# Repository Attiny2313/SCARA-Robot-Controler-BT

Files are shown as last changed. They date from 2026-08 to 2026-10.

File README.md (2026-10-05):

# SCARA Robot Controller

Open-source controller project for the **PyBot SCARA robotic arm** and compatible SCARA robots, based on an **ESP32 D1 Mini**, a custom PCB and Bluetooth gamepad control.

The repository contains firmware, editable EasyEDA electronics sources, Gerber files, technical documentation and 3D-printing resources used in the project.

## Current firmware

The current `main` branch includes:

- manual JOINT and TOOL control,
- TEACH point storage in ESP32 NVS,
- automatic PTP playback,
- AUTO speed override from 50% to 250%,
- startup OLED logo,
- assisted manual Z-axis HOME procedure after every restart,
- software E-STOP latch requiring controller restart,
- Polish, English and Ukrainian source comments,
- servo 2 startup position of 90° and allowed movement range of 90–180°.

## Startup procedure

ARM1 and ARM2 are positioned manually at `0°` before power-up or reset. After the controller starts, the firmware requires the operator to establish the Z-axis zero position:

1. Wait for the 5-second OLED startup logo.
2. Connect the Bluetooth gamepad and leave all controls neutral until the gamepad becomes armed.
3. Use the right stick Y axis to move Z at the reduced startup homing speed.
4. Set the mechanism physically at the intended `Z = 0` position.
5. Release the stick and wait until Z stops.
6. Press **A+B together** to confirm the current position as `Z = 0`.
7. Release A+B and leave the controller neutral again for normal MANUAL control to arm.

Normal MANUAL/AUTO operation and the MODE/TEACH panel buttons remain locked until Z HOME is confirmed.

## Controls

In MANUAL mode, `START` switches between JOINT and TOOL control.

- JOINT: left stick controls ARM1/ARM2, right stick Y controls Z.
- TOOL: left stick controls TCP X/Y, right stick Y controls Z.
- Right stick X controls tool rotation.
- A increases servo 2 angle, B decreases it; servo 2 is limited to 90–180°.
- PCB `MODE` switches MANUAL/AUTO when all axes are stopped.
- PCB `TEACH`: short press stores a point, hold for at least 1.8 s to clear the stored program.

In AUTO mode, `START` performs start/pause/resume. D-pad UP/DOWN changes speed by ±10%, while D-pad LEFT restores 100%.

## PC USB controller

The `dev` firmware also supports an optional desktop controller over USB Serial.
The physical Bluetooth gamepad remains supported; the PC application is a second,
exclusive input source with its own neutral-to-ARM safety procedure and a 600 ms
communication timeout.

Windows quick start:

```powershell
cd pc_controller
.\run_windows.bat
```

The application provides two virtual joysticks, gripper/relay controls, JOINT/TOOL,
MANUAL/AUTO, TEACH, startup Z HOME, AUTO speed controls and live robot position/status.

See [pc_controller/README.md](pc_controller/README.md) for details.

## Documentation

- [Documentation index](docs/README.md)
- [Robot operating instructions – Polish](docs/INSTRUKCJA_OBSLUGI_PL.md)
- [AUTO / TEACH reference](docs/AUTO_TEACH.md)
- [Technical documentation – Polish](docs/DOKUMENTACJA_TECHNICZNA_PL.md)
- [Technical documentation – Ukrainian](docs/DOKUMENTACJA_TECHNICZNA_UA.md)

## Repository contents

- `src/` – ESP32 controller firmware.
- `PCB/` – schematic, Gerbers, silkscreen and PCB documentation.
- `PCB/EasyEDA/` – editable EasyEDA schematic and PCB source files.
- `3DPrinting/` – printable mechanical parts.
- `docs/` – operating and technical documentation.

## Build and upload

1. Install Visual Studio Code.
2. Install the PlatformIO extension.
3. Download or clone this repository.
4. Open the project folder in PlatformIO.
5. Connect the ESP32.
6. Build and upload the firmware.

## Credits

### PyBot / jjRobots

The mechanical construction of this robot is based on the **PyBot SCARA Robotic Arm** by **jjRobots**.

Many thanks to jjRobots for publishing the original mechanical design, printable parts and assembly concept that formed the mechanical basis of this project.

- https://www.jjrobots.com/scara-robotic-arm-by-jjrobots/
- https://cults3d.com/en/3d-model/gadget/scara-robotic-arm-open-source-with-control-app

### Alternative gripper

The alternative gripper is based on **Robot Gripper 9g Micro Servo** by **yisparyan**:

- https://www.thingiverse.com/thing:715525

Many thanks to yisparyan for sharing the design with the robotics community.

## License

Original content created for this repository is released under the **MIT License**, unless otherwise marked. This includes the original controller firmware, project documentation and original project files.

Third-party material keeps its original license:

- PyBot-derived mechanical geometry: **CC BY-NC-SA** as published by jjRobots.
- Alternative gripper derived from Thingiverse thing 715525 by yisparyan: **CC BY**.
- External software dependencies retain their own upstream licenses.

Because the PyBot mechanical design includes a **NonCommercial** restriction, those particular third-party 3D assets are not relicensed under MIT and should not be treated as commercially unrestricted open-source content.

See [`LICENSE`](LICENSE), [`THIRD_PARTY_NOTICES.md`](THIRD_PARTY_NOTICES.md) and [`3DPrinting/README.md`](3DPrinting/README.md) for details.

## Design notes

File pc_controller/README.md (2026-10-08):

# SCARA Remote (PC / USB)

A small desktop controller for the SCARA firmware. It communicates with the ESP32
through the same USB serial port used by PlatformIO / Serial Monitor.

## Requirements

- Python 3.10+ recommended
- Tkinter (included with the standard Windows Python installer)
- pyserial

Install the dependency:

```powershell
cd pc_controller
py -m pip install -r requirements.txt
```

Run directly:

```powershell
py SCARA_Remote.py
```

On Windows you can also double-click `run_windows.bat`. It checks for `pyserial`,
installs it from `requirements.txt` when needed, and starts the controller.

Close PlatformIO Serial Monitor before connecting the application because only one
program can normally own the COM port at a time.

## Connection and safety

1. Connect the ESP32 over USB.
2. Start `SCARA_Remote.py`.
3. Select the ESP32 COM port and press **Połącz**.
4. The application performs the `PCHELLO` handshake automatically.
5. Leave both virtual joysticks and all buttons neutral for at least 300 ms.
6. The status changes from **SAFE** to **ARMED**.
7. After every ESP32 restart, establish Z HOME before normal MANUAL operation.

The firmware expects a fresh `PCPAD` packet continuously. If packets stop for more
than 600 ms, manual motion is stopped. If AUTO is running, it is paused.

The physical E-STOP remains authoritative.

## Controls

- Left virtual joystick: ARM1/ARM2 in JOINT, TCP X/Y in TOOL.
- Right virtual joystick: rotation on X and Z on Y.
- **A / B**: gripper.
- **X**: relay.
- **START**: JOINT / TOOL in MANUAL; start / pause / resume in AUTO.
- **MODE**: MANUAL / AUTO.
- **TEACH / Zapisz punkt**: sends a dedicated save command to the ESP32.
- **KASUJ PROGRAM**: asks for confirmation and sends a dedicated clear command.
- The physical PCB TEACH button still keeps its original behavior: short press saves, hold at least 1.8 s clears.
- **HOME Z A+B**: confirms startup Z HOME when Z is stopped.
- AUTO D-pad: up/down changes speed, left restores 100%.

Keyboard shortcuts:

- `W A S D` - left joystick
- `I J K L` - right joystick
- `Q / E` - A / B
- `R` - relay
- `Space` - START
- `M` - MODE
- `T` - TEACH
- `H` - A+B for startup Z HOME
- Arrow keys - AUTO D-pad

## Serial protocol

The desktop app sends:

```text
PCHELLO
PCPAD,LX,LY,RX,RY,BUTTONS,DPAD
PCTEACH
PCCLEAR
PCBYE
```

Axes are integers from `-1000` to `1000`.

Button mask:

- bit 0 = A
- bit 1 = B
- bit 2 = X
- bit 3 = START
- bit 4 = MODE
- bit 5 = TEACH

D-pad mask:

- bit 0 = UP
- bit 1 = DOWN
- bit 2 = LEFT
- bit 3 = RIGHT

The firmware returns machine-readable status lines beginning with `PCSTATE,`.

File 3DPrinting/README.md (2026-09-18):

# 3D printing files

This directory contains printable files used by the SCARA project. Some files are based on third-party designs and therefore keep their original licenses.

## `Parts set.3mf`

The robot mechanical construction is based on the **PyBot SCARA Robotic Arm** by **jjRobots**.

Original project:
- https://www.jjrobots.com/scara-robotic-arm-by-jjrobots/
- https://cults3d.com/en/3d-model/gadget/scara-robotic-arm-open-source-with-control-app

The PyBot design is published under **Creative Commons Attribution-NonCommercial-ShareAlike (CC BY-NC-SA)**. Any geometry originating from or derived from PyBot remains under that upstream license.

Many thanks to **jjRobots** for the original mechanical design and for making the project available to the maker and robotics community.

## `Alternative gripper.3mf`

The alternative gripper is based on **Robot Gripper 9g Micro Servo** by **yisparyan**:

- https://www.thingiverse.com/thing:715525

The original gripper is published under **Creative Commons Attribution (CC BY)**. Attribution to yisparyan and the original Thingiverse design must be retained when redistributing this file or derivatives.

Many thanks to **yisparyan** for sharing the gripper design.

## Important

The repository root MIT license does not override the licenses of the third-party models listed above. See `../THIRD_PARTY_NOTICES.md` for the complete attribution and license summary.

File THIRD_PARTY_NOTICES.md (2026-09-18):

# Third-party notices and credits

This repository contains original work from the SCARA Robot Controller project as well as material based on third-party open designs. The root `LICENSE` (MIT) applies only to original project content unless a file or directory is explicitly identified below as third-party material.

## PyBot / jjRobots mechanical design

The mechanical construction of this project is based on the **PyBot SCARA Robotic Arm** created by **jjRobots**.

We would like to thank jjRobots for publishing the original mechanical design, printable parts and assembly concept that made this project possible.

Sources:
- https://www.jjrobots.com/scara-robotic-arm-by-jjrobots/
- https://cults3d.com/en/3d-model/gadget/scara-robotic-arm-open-source-with-control-app

The published PyBot 3D design is distributed under **Creative Commons Attribution-NonCommercial-ShareAlike (CC BY-NC-SA)**. The source page retrieved for this project does not identify the Creative Commons version number, so this notice intentionally does not assume one.

Any PyBot-derived geometry included in this repository remains subject to the original PyBot license and is **not relicensed under MIT**.

## Alternative gripper – yisparyan / Thingiverse 715525

The alternative gripper used in this project is based on **Robot Gripper 9g Micro Servo** by **yisparyan**:

- https://www.thingiverse.com/thing:715525

Thank you to yisparyan for publishing the gripper design and making it available for reuse.

The original model is published under **Creative Commons Attribution (CC BY)**. The source information retrieved for this project does not identify the Creative Commons version number, so this notice intentionally does not assume one.

The file `3DPrinting/Alternative gripper.3mf` is therefore subject to the attribution requirements of the original CC BY license and is **not relicensed under MIT**.

## External software libraries

Libraries and frameworks referenced by `platformio.ini`, including Arduino/ESP32, Bluepad32, FastAccelStepper, ESP32Servo, Adafruit GFX and Adafruit SSD1306, remain subject to their own upstream licenses. They are not relicensed by this repository.

## License scope summary

- Original firmware, PCB-related project files, documentation and other original project material: **MIT License**, unless otherwise marked.
- PyBot-derived mechanical geometry: **CC BY-NC-SA**, as published by jjRobots.
- Alternative gripper derived from Thingiverse thing 715525 by yisparyan: **CC BY**, as published by the original author.
- External dependencies: their respective upstream licenses.

If an upstream license notice conflicts with this summary, the upstream license notice takes precedence for that third-party material.

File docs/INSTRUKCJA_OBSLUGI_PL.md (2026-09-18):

# INSTRUKCJA OBSŁUGI ROBOTA SCARA

## 1. Przeznaczenie

Robot jest edukacyjnym manipulatorem SCARA przeznaczonym do nauki programowania, automatyki, robotyki, kinematyki i pracy metodą TEACH. Sterowanie odbywa się z wykorzystaniem ESP32, dedykowanej płytki PCB, silników krokowych, dwóch serwomechanizmów i kontrolera Bluetooth.

Urządzenie ma charakter dydaktyczny i eksperymentalny. Nie jest certyfikowanym robotem przemysłowym.

## 2. Elementy sterowania

Robot posiada:

- kontroler Bluetooth,
- przycisk `MODE` na PCB,
- przycisk `TEACH` na PCB,
- E-STOP,
- diodę Bluetooth,
- diodę STATUS,
- diodę ERROR,
- wyświetlacz OLED 128×64.

## 3. Pozycja startowa

Przed włączeniem zasilania lub wykonaniem resetu należy ręcznie ustawić:

- ARM1: `0°`,
- ARM2: `0°`.

Oś Z nie musi być wcześniej ustawiona dokładnie na zero. Jej punkt HOME ustala się po uruchomieniu z wykorzystaniem pada.

Pozycje startowe serw:

- serwo 1 – obrót narzędzia: `90°`,
- serwo 2 – chwytak: `90°`.

Zakres serwa 2 jest ograniczony programowo do `90–180°`.

## 4. Uruchomienie robota

1. Sprawdź, czy w zasięgu robota nie znajdują się osoby ani przedmioty mogące wejść w kolizję z ramieniem.
2. Ustaw ręcznie ARM1 i ARM2 na `0°`.
3. Zwolnij E-STOP.
4. Włącz zasilanie lub zresetuj ESP32.
5. OLED przez około 5 s wyświetli logo startowe.
6. Następnie pojawi się ekran `SET Z HOME`.
7. Połącz pad Bluetooth ze sterownikiem.
8. Nie dotykaj analogów ani przycisków przez co najmniej 300 ms, aż pad zostanie uzbrojony.
9. Wykonaj procedurę HOME osi Z opisaną w następnym rozdziale.

Do momentu zatwierdzenia HOME Z normalne sterowanie, `MODE` i `TEACH` pozostają zablokowane.

## 5. Ustawianie HOME osi Z

Podczas startowej procedury HOME Z:

- prawy analog Y steruje wyłącznie osią Z,
- maksymalna prędkość ruchu wynosi około `1.5 mm/s`,
- normalne programowe ograniczenie `0–300 mm` nie jest jeszcze używane, ponieważ sterownik nie zna pozycji absolutnej.

Procedura:

1. Poruszaj osią Z prawym analogiem Y.
2. Ustaw mechanicznie pozycję, która ma odpowiadać `Z = 0`.
3. Puść analog.
4. Poczekaj, aż oś Z całkowicie się zatrzyma.
5. Naciśnij jednocześnie `A+B`.
6. Sterownik przypisze aktualnej pozycji wartość `Z = 0.00 mm`.
7. Puść oba przyciski.
8. Pozostaw pad neutralnie przez około 300 ms, aby ponownie uzbroić normalne sterowanie MANUAL.

Po zatwierdzeniu Z HOME nie należy ręcznie przestawiać osi ani ramion. Sterownik nie ma enkoderów i nie wykryje takiej zmiany.

## 6. Tryb MANUAL – JOINT

Po uruchomieniu robot pracuje w trybie MANUAL. `START` na padzie przełącza między `JOINT` i `TOOL`.

W trybie JOINT sterowanie jest bezpośrednie:

| Element pada | Funkcja |
|---|---|
| Lewy analog X | ARM1 |
| Lewy analog Y | ARM2 |
| Prawy analog Y | Oś Z |
| Prawy analog X | Obrót narzędzia – serwo 1 |
| A | Zwiększenie kąta serwa 2 |
| B | Zmniejszenie kąta serwa 2 |
| START | Przełączenie JOINT / TOOL |

Programowe zakresy osi:

- ARM1: `−105° ... +105°`,
- ARM2: `−125° ... +125°`,
- Z: `0 ... 300 mm`,
- serwo 1: `0 ... 180°`,
- serwo 2: `90 ... 180°`.

## 7. Tryb MANUAL – TOOL

W trybie TOOL operator steruje pozycją końcówki TCP w płaszczyźnie XY, a sterownik sam przelicza wymagane kąty ARM1 i ARM2 przy pomocy kinematyki odwrotnej.

| Element pada | Funkcja |
|---|---|
| Lewy analog X | TCP w osi X |
| Lewy analog Y | TCP w osi Y |
| Prawy analog Y | Oś Z |
| Prawy analog X | Obrót narzędzia |
| A / B | Zmiana kąta serwa 2 |
| START | Powrót do JOINT |

Jeżeli żądany punkt XY znajduje się poza przestrzenią roboczą lub rozwiązanie kinematyki jest niedozwolone, ruch zostanie odrzucony i może zapalić się dioda ERROR.

## 8. Zapisywanie punktów TEACH

Punkty można zapisywać tylko w MANUAL i przy zatrzymanych osiach.

Krótko naciśnij przycisk `TEACH` na PCB, aby zapisać aktualny punkt.

Zapisywane są:

- pozycja ARM1,
- pozycja ARM2,
- pozycja Z,
- pozycja serwa 1,
- pozycja serwa 2,
- czas postoju punktu.

Sterownik przechowuje maksymalnie 20 punktów. Punkty są zapisywane w pamięci NVS i pozostają po odłączeniu zasilania.

Aby skasować cały program, przytrzymaj `TEACH` przez co najmniej `1.8 s`.

## 9. Tryb AUTO

Do AUTO można przejść tylko przy zatrzymanych osiach.

1. Zatrzymaj robota.
2. Naciśnij `MODE` na PCB.
3. Dioda STATUS powinna wskazać tryb AUTO.
4. Naciśnij `START` na padzie, aby rozpocząć program.

`START` w AUTO działa kolejno jako:

- start,
- pauza,
- wznowienie.

Program odtwarza zapisane punkty metodą PTP i domyślnie pracuje w pętli.

## 10. Regulacja prędkości AUTO

Prędkość AUTO można zmieniać D-padem:

- D-pad góra: `+10%`,
- D-pad dół: `−10%`,
- D-pad lewo: powrót do `100%`.

Dostępny zakres to `50–250%`.

Bazowe prędkości wynoszą:

- ARM1: `20°/s`,
- ARM2: `20°/s`,
- Z: `3.0 mm/s`.

Zmiana procentu zaczyna obowiązywać od kolejnego punktu PTP i skaluje wszystkie trzy główne osie.

## 11. Zatrzymanie programu AUTO

Naciśnięcie `START` podczas ruchu przełącza AUTO w PAUSE.

Po ponownym naciśnięciu `START` program jest wznawiany od bieżącego punktu.

Rozłączenie pada podczas AUTO również powoduje pauzę programu.

## 12. E-STOP

E-STOP należy nacisnąć natychmiast w przypadku:

- zagrożenia kolizją,
- niekontrolowanego ruchu,
- zablokowania mechaniki,
- problemu z napędem,
- zagrożenia dla operatora lub urządzenia.

Po aktywacji E-STOP firmware:

- zatrzymuje generowanie kroków,
- blokuje ruch,
- ustawia AUTO w stan FAULT,
- zapala sygnalizację błędu.

Po E-STOP wymagany jest restart sterownika. Po restarcie należy ponownie ustawić ARM1/ARM2 na `0°` i wykonać HOME Z.

## 13. Sygnalizacja

### LED Bluetooth

- światło ciągłe – pad połączony,
- miganie – brak połączenia z padem.

### LED STATUS

- świeci w trybie AUTO,
- zgaszona w MANUAL.

### LED ERROR

Może sygnalizować m.in.:

- timeout pada,
- niedozwolony punkt TOOL / błąd IK,
- E-STOP,
- FAULT AUTO.

### OLED

OLED pokazuje zależnie od stanu m.in.:

- ekran startowy,
- procedurę `SET Z HOME`,
- stan połączenia Bluetooth,
- uzbrojenie pada,
- tryb MANUAL/AUTO,
- JOINT/TOOL,
- położenie osi,
- liczbę punktów TEACH,
- stan programu AUTO,
- procent prędkości AUTO.

## 14. Utrata kroków i pozycja robota

Pozycja robota jest obliczana z liczników kroków silników. Sterownik nie otrzymuje sprzężenia zwrotnego z enkoderów.

Jeżeli silnik zgubi kroki:

- pozycja programowa przestaje odpowiadać rzeczywistej,
- zapis kolejnych punktów TEACH może być błędny,
- AUTO może pojechać do innego miejsca niż oczekiwane.

W takiej sytuacji należy zatrzymać robota i wykonać restart oraz ponowne ustawienie HOME.

## 15. Zasady bezpiecznej pracy

- Nie wkładaj rąk w przestrzeń roboczą podczas ruchu.
- Nie zmieniaj ręcznie położenia osi po ustaleniu HOME.
- Nie zapisuj punktu TEACH podczas ruchu.
- Nie przełączaj MANUAL/AUTO podczas ruchu.
- Pierwsze odtworzenie nowego programu wykonuj z obniżoną prędkością AUTO.
- Obserwuj przewody, paski, śrubę Z i chwytak pod kątem kolizji.
- Po każdej zmianie mechanicznej lub zmianie przełożenia zweryfikuj parametry firmware.
- Nie odłączaj silnika krokowego od sterownika przy załączonym zasilaniu.
- E-STOP powinien być zawsze łatwo dostępny.

## 16. Zalecana procedura pierwszego uruchomienia programu

1. Uruchom robota i wykonaj HOME Z.
2. Pozostań w MANUAL.
3. Sprawdź każdy kierunek ruchu osi przy małym wychyleniu analogu.
4. Sprawdź zakres serw.
5. Zapisz 2–3 bezpieczne punkty TEACH z dużym zapasem od przeszkód.
6. Przejdź do AUTO.
7. Ustaw prędkość na `50%`.
8. Uruchom program i trzymaj rękę w pobliżu E-STOP.
9. Po potwierdzeniu poprawnego przebiegu stopniowo zwiększaj prędkość.

## 17. Wyłączenie robota

1. Zatrzymaj ruch.
2. Jeżeli działa AUTO, przełącz go w PAUSE lub wróć do MANUAL.
3. Ustaw mechanikę w bezpiecznej pozycji.
4. Wyłącz zasilanie.

Po kolejnym włączeniu zawsze należy ponownie wykonać procedurę HOME osi Z.

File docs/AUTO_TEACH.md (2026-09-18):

# AUTO / TEACH – aktualny firmware `main`

## Pozycja HOME

Robot nie wykonuje automatycznego homingu wszystkich osi.

Pozycja startowa jest ustalana w dwóch etapach:

- ARM1: operator ręcznie ustawia mechanikę na `0°` przed włączeniem zasilania lub resetem,
- ARM2: operator ręcznie ustawia mechanikę na `0°` przed włączeniem zasilania lub resetem,
- Z: po restarcie operator ustawia fizyczne zero osią sterowaną z pada i zatwierdza je kombinacją `A+B`.

### Startowe ustawianie Z HOME

Po uruchomieniu sterownika:

1. OLED wyświetla logo przez 5 s.
2. Następnie pojawia się ekran `SET Z HOME`.
3. Pad musi być połączony i uzbrojony przez pozostawienie wszystkich wejść w neutralnym położeniu przez 300 ms.
4. Prawy analog Y steruje wyłącznie osią Z z prędkością maksymalną `1.5 mm/s`.
5. Po puszczeniu analogu Z jest natychmiast zatrzymywana.
6. Po ustawieniu mechanicznego zera operator, przy zatrzymanej osi, naciska jednocześnie `A+B`.
7. Bieżąca pozycja licznika kroków zostaje wtedy ustawiona jako `Z = 0.00 mm`.
8. Pad jest ponownie rozbrajany; po puszczeniu `A+B` trzeba pozostawić go neutralnie przez 300 ms.

Do chwili zatwierdzenia Z HOME normalne sterowanie MANUAL/AUTO oraz przyciski MODE i TEACH są zablokowane.

## Tryby pracy

Sterownik ma dwa niezależne poziomy trybów:

- `OperatingMode::MANUAL` / `OperatingMode::AUTO`,
- w MANUAL: `ControlMode::JOINT` / `ControlMode::TOOL`.

JOINT/TOOL określa sposób ręcznego prowadzenia robota, a AUTO jest osobnym trybem pracy.

## Przyciski na PCB

### MODE

Przełącza `MANUAL <-> AUTO`.

Zmiana jest odrzucana, gdy którakolwiek oś jest w ruchu. Po przejściu z AUTO do MANUAL pad musi ponownie przejść neutralne uzbrojenie.

### TEACH

Działa tylko w MANUAL i przy zatrzymanych osiach.

- krótkie naciśnięcie: zapis aktualnego punktu,
- przytrzymanie `>= 1.8 s`: wyczyszczenie całego programu.

Punkt zapisuje:

- rzeczywistą pozycję ARM1,
- rzeczywistą pozycję ARM2,
- rzeczywistą pozycję Z,
- pozycję serwa obrotu narzędzia,
- pozycję serwa 2 / chwytaka,
- czas postoju `dwellMs`.

Program może zawierać maksymalnie 20 punktów. Punkty są przechowywane w NVS ESP32 i pozostają po wyłączeniu zasilania.

## Pad – MANUAL

`START` przełącza JOINT / TOOL.

### JOINT

- lewy analog X – ARM1,
- lewy analog Y – ARM2,
- prawy analog Y – Z,
- prawy analog X – obrót narzędzia,
- A – zwiększa kąt serwa 2,
- B – zmniejsza kąt serwa 2.

### TOOL

- lewy analog X/Y – ruch TCP w X/Y przez kinematykę odwrotną,
- prawy analog Y – Z,
- prawy analog X – obrót narzędzia,
- A/B – zmiana kąta serwa 2.

Po połączeniu pada wymagane jest 300 ms neutralnych wejść przed uzbrojeniem ruchu.

### Zakresy serw

- serwo obrotu narzędzia: `0 ... 180°`, pozycja startowa `90°`,
- serwo 2 / chwytak: `90 ... 180°`, pozycja startowa `90°`.

## Pad – AUTO

`START` działa jako:

- IDLE -> START,
- RUN -> PAUSE,
- PAUSED -> RESUME.

Regulacja prędkości całego ruchu w AUTO:

- D-pad góra: `+10%`,
- D-pad dół: `-10%`,
- D-pad lewo: powrót do `100%`,
- zakres regulacji: `50% ... 250%`,
- regulacja skaluje ARM1, ARM2 oraz Z,
- nowa wartość obowiązuje od następnego punktu PTP; bieżący ruch nie jest przeliczany w locie.

Bazowo oba ramiona w AUTO mają `20 deg/s`, a oś Z `3.0 mm/s`. Przykładowo przy `200%` ramiona mają bazową prędkość `40 deg/s`, a Z `6.0 mm/s`.

Sterownik nie nakłada dodatkowego programowego limitu częstotliwości STEP; rzeczywista granica wynika z możliwości napędu, sterownika i mechaniki.

Utrata pada podczas AUTO przełącza program w PAUSE.

## Cykl AUTO

AUTO odtwarza zapisane punkty jako ruch PTP. Dla każdego punktu:

1. ustawiane są cele serw,
2. obliczane są odległości wszystkich trzech osi,
3. dobierane są częstotliwości STEP tak, aby osie w przybliżeniu kończyły ruch w tym samym czasie,
4. sterownik czeka nieblokująco na zakończenie wszystkich osi,
5. wykonywany jest `dwellMs`,
6. uruchamiany jest kolejny punkt.

Domyślnie program pracuje w pętli (`AUTO_LOOP_PROGRAM = true`).

## Sygnalizacja

- LED Bluetooth: świeci ciągle przy połączonym padzie, miga przy braku połączenia,
- LED STATUS: świeci w trybie AUTO,
- LED ERROR: sygnalizuje m.in. timeout pada, błąd IK, E-STOP lub FAULT AUTO,
- OLED: pokazuje tryb, stan pada, położenia osi, liczbę punktów i stan AUTO.

## Bezpieczeństwo

- E-STOP natychmiast zatrzymuje generowanie kroków i ustawia AUTO w `FAULT`.
- Po E-STOP wymagany jest restart sterownika.
- AUTO nie jest zależne od `gamepadArmed`; blokada `gamepadArmed` dotyczy ruchu ręcznego.
- Do AUTO wykorzystywana jest pozycja liczona z `FastAccelStepper::getCurrentPosition()`.
- Sterownik nie ma enkoderów osi, dlatego utrata kroków powoduje utratę zgodności pozycji programowej z mechaniczną.
- Po każdym restarcie należy ponownie wykonać procedurę Z HOME.

## Kolejny etap

Obecna wersja AUTO realizuje PTP. Możliwym kolejnym rozszerzeniem jest interpolacja `LIN`, w której TCP jest dzielony na krótkie odcinki XYZ, a dla kolejnych próbek wykonywana jest kinematyka odwrotna.

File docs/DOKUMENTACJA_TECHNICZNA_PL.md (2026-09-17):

# DOKUMENTACJA TECHNICZNA
## ROBOTYCZNE RAMIĘ SCARA
### Projekt „Robotyka bez granic”

**Typ urządzenia:** edukacyjne ramię robotyczne SCARA 3 DOF + chwytak 2 DOF  
**Sterownik:** ESP32 D1 Mini / WeMos D1 Mini ESP32  
**Sterowanie:** kontroler Bluetooth + przyciski na płytce  
**Oprogramowanie:** C++ / Arduino Framework / PlatformIO  
**Repozytorium:** `Attiny2313/SCARA-Robot-Controler-BT`  
**Gałąź odpowiadająca niniejszemu opisowi:** `dev`  
**Bazowy commit firmware/config:** `3dcf2272da6c95ba952772bd750d242ef21eb560`  

> Dokument opisuje rzeczywistą wersję projektu rozwijaną w repozytorium. Dane pochodzące z projektu bazowego PyBot zostały oddzielone od parametrów wynikających z aktualnej konstrukcji i programu sterującego.

---

# 1. CEL PROJEKTU

Celem projektu jest wykonanie, uruchomienie i zaprogramowanie edukacyjnego robota typu SCARA (Selective Compliance Assembly Robot Arm), przeznaczonego do nauki zagadnień z zakresu mechaniki, elektroniki, automatyki, robotyki, programowania oraz technologii druku 3D.

Robot umożliwia:

- ręczne sterowanie poszczególnymi osiami,
- sterowanie położeniem końcówki roboczej w układzie kartezjańskim,
- sterowanie chwytakiem,
- zapisywanie punktów metodą TEACH,
- automatyczne odtwarzanie zapisanej sekwencji ruchów,
- realizację zadań typu Pick and Place,
- dalszą rozbudowę o dodatkowe czujniki, system wizyjny i inne narzędzia robocze.

Projekt ma charakter edukacyjny i eksperymentalny. Nie jest urządzeniem przemysłowym ani certyfikowanym robotem przeznaczonym do pracy w środowisku produkcyjnym.

---

# 2. CHARAKTERYSTYKA ROBOTA

Robot jest manipulatorem typu SCARA, którego główna część wykonawcza składa się z:

- osi obrotowej ARM1,
- osi obrotowej ARM2,
- liniowej osi pionowej Z,
- serwomechanizmu obrotu chwytaka,
- serwomechanizmu otwierania i zamykania chwytaka.

Za ruch trzech głównych osi odpowiadają silniki krokowe NEMA 17. Ruch obrotowy chwytaka i jego otwieranie realizują serwomechanizmy.

Konstrukcja mechaniczna bazuje na rozwiązaniach projektu PyBot i wykorzystuje elementy wykonane metodą druku 3D oraz standardowe elementy mechaniczne stosowane m.in. w drukarkach 3D.

Sterowanie realizuje mikrokontroler ESP32 współpracujący z dedykowaną płytką PCB. ESP32 komunikuje się z bezprzewodowym kontrolerem poprzez Bluetooth i samodzielnie realizuje logikę sterowania, kinematykę, generację trajektorii PTP, obsługę TEACH/AUTO oraz zabezpieczenia programowe.

Komputer nie jest wymagany do normalnej pracy robota. Jest wykorzystywany do programowania, aktualizacji firmware oraz diagnostyki przez port szeregowy.

---

# 3. PARAMETRY TECHNICZNE

## 3.1. Parametry konstrukcji i sterowania

| Parametr | Wartość |
|---|---:|
| Typ robota | SCARA |
| Liczba głównych osi | 3 |
| Osie robocze | ARM1, ARM2, Z |
| Dodatkowe osie chwytaka | 2 |
| Silniki główne | 3 × NEMA 17 |
| Kąt pełnego kroku silnika | 1,8° |
| Liczba pełnych kroków na obrót | 200 |
| Mikrokrok | 1/16 |
| Serwomechanizmy | 2 × klasy SG90/MG90/MG92R |
| Sterownik główny | ESP32 D1 Mini |
| Sterowniki silników | A4988 |
| Środowisko programistyczne | PlatformIO / Visual Studio Code |
| Framework | Arduino |
| Język programu | C++ |
| Komunikacja z padem | Bluetooth / Bluepad32 |

## 3.2. Parametry wykorzystywane przez aktualny firmware

| Parametr | Wartość |
|---|---:|
| Długość członu ARM1 | 91,61 mm |
| Długość członu ARM2 | 97,528 mm |
| Przełożenie ARM1 | 4,5 |
| Przełożenie ARM2 | 7,280 |
| Skok śruby osi Z | 2,0 mm/obr. |
| Przełożenie Z | 1,0 |
| Zakres programowy ARM1 | −105° ... +105° |
| Zakres programowy ARM2 | −125° ... +125° |
| Zakres programowy Z | 0 ... 300 mm |
| Zakres obrotu chwytaka | 0 ... 180° |
| Zakres serwa chwytaka | 15 ... 95° |
| Prędkość ręczna ARM1 | 25°/s |
| Prędkość ręczna ARM2 | 25°/s |
| Prędkość ręczna Z | 3,0 mm/s |
| Prędkość TCP w trybie TOOL | 20 mm/s |
| Bazowa prędkość AUTO ARM1 | 20°/s |
| Bazowa prędkość AUTO ARM2 | 20°/s |
| Bazowa prędkość AUTO Z | 3,0 mm/s |
| Override prędkości AUTO | 50...250% dla ARM1, ARM2 i Z |
| Przyspieszenie ARM1 | 12000 STEP/s² |
| Przyspieszenie ARM2 | 5000 STEP/s² |
| Przyspieszenie Z | 6000 STEP/s² |
| Liczba punktów programu TEACH | maks. 20 |

## 3.3. Parametry wymagające pomiaru rzeczywistego egzemplarza

Nie należy bez dodatkowych pomiarów przyjmować wartości deklarowanych dla bazowego projektu PyBot jako parametrów gotowego robota.

W szczególności wymagają pomiaru:

- rzeczywista masa robota,
- rzeczywista przestrzeń robocza,
- rzeczywista powtarzalność pozycjonowania,
- maksymalny bezpieczny udźwig,
- maksymalne praktyczne prędkości osi,
- dokładność pozycjonowania TCP.

Do czasu wykonania prób odbiorczych wartości te powinny być traktowane jako „do wyznaczenia”.

---

# 4. BUDOWA MECHANICZNA

## 4.1. Podstawa

Podstawa stanowi element nośny całej konstrukcji. Mocowane są do niej m.in.:

- prowadnice osi Z,
- napędy,
- elementy przekładni pasowych,
- elektronika sterująca,
- elementy zabezpieczające przewody.

Podstawa powinna zapewniać sztywność konstrukcji oraz możliwość stabilnego ustawienia robota na stanowisku.

## 4.2. Pierwszy człon ramienia – ARM1

Pierwszy człon łączy podstawę z centralnym przegubem robota. Jego ruch zmienia kierunek całego manipulatora w płaszczyźnie XY.

Napęd realizowany jest silnikiem krokowym poprzez przekładnię pasową.

## 4.3. Drugi człon ramienia – ARM2

Drugi człon łączy pierwszy człon z końcówką roboczą. Wspólnie z osią ARM1 określa położenie TCP w płaszczyźnie XY.

Ruch realizowany jest niezależnym napędem krokowym poprzez układ przekładni pasowych.

## 4.4. Oś pionowa Z

Oś Z realizuje ruch pionowy końcówki roboczej. Napęd odbywa się za pomocą silnika krokowego i śruby o skoku 2 mm/obrót.

Ze względu na dużą liczbę kroków przypadających na 1 mm ruchu oraz ryzyko gubienia kroków, oś Z pracuje z wyraźnie niższą prędkością niż osie obrotowe.

## 4.5. Chwytak

Chwytak jest wyposażony w dwa serwomechanizmy:

- serwo obrotu narzędzia,
- serwo otwierania i zamykania chwytaka.

Położenia serw mogą być zapisywane razem z punktami programu TEACH.

---

# 5. UKŁAD NAPĘDOWY

## 5.1. Silniki krokowe

Każda z trzech głównych osi korzysta z silnika NEMA 17 o kącie pełnego kroku 1,8°.

Pełny obrót odpowiada:

`360° / 1,8° = 200 kroków`

Przy zastosowaniu mikrokroku 1/16:

`200 × 16 = 3200 mikrokroków na obrót silnika`

Dodatkowo liczba kroków roboczych jest zależna od przełożenia danej osi.

Dla osi Z, przy skoku śruby 2 mm/obrót i mikrokroku 1/16:

`3200 / 2 = 1600 kroków/mm`

Wartość ta jest wykorzystywana przez firmware do przeliczania położenia osi Z.

## 5.2. Sterowniki A4988

Sterowniki A4988 odpowiadają za zasilanie i sterowanie silników krokowych. Każdy sterownik otrzymuje z ESP32 sygnały:

- STEP,
- DIR.

Należy prawidłowo ustawić prąd sterowników zgodnie z zastosowanymi silnikami i chłodzeniem.

Nie wolno podłączać ani odłączać silnika krokowego przy załączonym zasilaniu sterownika.

---

# 6. UKŁAD ELEKTRYCZNY I ELEKTRONICZNY

## 6.1. Główne elementy

Układ elektroniczny zawiera:

- ESP32 D1 Mini,
- 3 sterowniki A4988,
- przetwornicę LM2596,
- złącza silników,
- złącza serwomechanizmów,
- przyciski TEACH i MODE,
- obwód E-STOP,
- diody sygnalizacyjne,
- wyświetlacz OLED SSD1306 128×64 I2C,
- złącza krańcówek,
- elementy bierne i zabezpieczające.

Dokumentacja płytki PCB znajduje się w katalogu `PCB` repozytorium.

## 6.2. Przypisanie wejść i wyjść ESP32

| Funkcja | GPIO |
|---|---:|
| STEP ARM1 | 13 |
| DIR ARM1 | 26 |
| STEP ARM2 | 23 |
| DIR ARM2 | 14 |
| STEP Z | 18 |
| DIR Z | 19 |
| Servo ROTATE | 27 |
| Servo GRIP | 32 |
| TEACH | 25 |
| MODE | 33 |
| E-STOP | 39 |
| Krańcówka Z | 34 |
| Krańcówka ARM1 | 35 |
| Krańcówka ARM2 | 36 |
| LED Bluetooth | 4 |
| LED ERROR | 16 |
| LED STATUS | 17 |
| I2C SDA (OLED) | 21 |
| I2C SCL (OLED) | 22 |

## 6.3. Krańcówki

Płytka posiada wejścia dla krańcówek osi ARM1, ARM2 i Z.

W aktualnej wersji firmware krańcówki nie realizują automatycznego homingu. Wejścia zostały zachowane sprzętowo na potrzeby przyszłej rozbudowy.

## 6.4. E-STOP

E-STOP jest elementem bezpieczeństwa układu.

Po jego aktywacji firmware:

- natychmiast zatrzymuje generowanie kroków,
- blokuje sterowanie ręczne,
- ustawia program AUTO w stan FAULT,
- sygnalizuje błąd,
- wymaga restartu sterownika przed ponowną pracą.

Układ powinien być wykonany tak, aby E-STOP nie opierał się wyłącznie na programie, lecz dodatkowo ograniczał możliwość dalszego zasilania lub aktywacji napędów zgodnie z założeniami płytki sterującej.

## 6.5. Wyświetlacz OLED

Sterownik obsługuje wyświetlacz OLED SSD1306 128×64 podłączony przez I2C. Magistrala wykorzystuje GPIO21 jako SDA i GPIO22 jako SCL.

Podczas inicjalizacji firmware automatycznie sprawdza adresy `0x3C` i `0x3D`. Brak wyświetlacza nie blokuje pracy robota — informacja o problemie jest wysyłana przez Serial.

W czasie pracy OLED pokazuje m.in.:

- tryb MANUAL/AUTO i stan programu,
- stan połączenia Bluetooth,
- liczbę zapisanych punktów TEACH,
- override prędkości w AUTO,
- aktualne położenia ARM1, ARM2 i Z,
- pozycję TCP X/Y lub numer aktualnego punktu programu,
- stany błędów, w tym `E-STOP` i `NUM ERR`.

---

# 7. ARCHITEKTURA STEROWANIA

Rzeczywisty przepływ sterowania można przedstawić następująco:

`Pad Bluetooth → Bluepad32 → ESP32 → logika sterowania → kinematyka / AUTO → FastAccelStepper → A4988 → silniki NEMA17`

Równolegle:

`ESP32 → ESP32Servo → serwo obrotu + serwo chwytaka`

ESP32 pełni jednocześnie funkcję:

- odbiornika poleceń,
- sterownika osi,
- sterownika serw,
- układu kinematyki,
- generatora sekwencji AUTO,
- pamięci programu TEACH,
- modułu bezpieczeństwa programowego,
- układu diagnostycznego.

---

# 8. OPROGRAMOWANIE

## 8.1. Środowisko

Program sterujący został przygotowany w języku C++ z wykorzystaniem:

- Arduino Framework,
- PlatformIO,
- Visual Studio Code.

## 8.2. Główne biblioteki

### Bluepad32

Biblioteka odpowiada za obsługę kontrolerów Bluetooth.

### FastAccelStepper

Biblioteka generuje sygnały STEP dla trzech osi i umożliwia definiowanie prędkości, przyspieszeń oraz pozycji.

### ESP32Servo

Biblioteka steruje serwomechanizmami chwytaka.

### Preferences

Biblioteka obsługuje pamięć NVS ESP32. W pamięci zapisywany jest program TEACH, dzięki czemu punkty pozostają dostępne po wyłączeniu zasilania.

### Adafruit GFX / Adafruit SSD1306

Biblioteki odpowiadają za obsługę wyświetlacza OLED SSD1306 128×64, prezentację stanu robota oraz podstawową diagnostykę.

---

# 9. TRYBY PRACY

Sterownik wykorzystuje dwa niezależne poziomy trybów.

## 9.1. Tryb pracy głównej

- `MANUAL`
- `AUTO`

## 9.2. Tryb sterowania ręcznego

W trybie MANUAL dostępne są:

- `JOINT`
- `TOOL`

Dzięki temu wybór JOINT/TOOL nie jest tym samym co wybór MANUAL/AUTO.

---

# 10. STEROWANIE RĘCZNE – JOINT

W trybie JOINT operator steruje bezpośrednio poszczególnymi osiami robota.

Aktualne mapowanie pada:

| Element kontrolera | Funkcja |
|---|---|
| Lewy analog X | ARM1 |
| Lewy analog Y | ARM2 |
| Prawy analog Y | Z |
| Prawy analog X | obrót chwytaka |
| A / B | otwieranie / zamykanie chwytaka |
| START | JOINT / TOOL |

Wartości z analogów są normalizowane i posiadają martwą strefę, aby niewielkie odchylenia drążka nie powodowały ruchu robota.

Po połączeniu kontrolera robot nie zostaje od razu uzbrojony. Wymagane jest około 300 ms neutralnego położenia wszystkich elementów sterujących. Rozwiązanie to zapobiega niekontrolowanemu ruchowi tuż po sparowaniu pada.

---

# 11. STEROWANIE RĘCZNE – TOOL

W trybie TOOL operator nie steruje bezpośrednio kątami ARM1 i ARM2.

Lewy analog zadaje ruch końcówki roboczej w płaszczyźnie XY, a program oblicza wymagane kąty ramion za pomocą kinematyki odwrotnej.

Sterowanie osi Z i chwytakiem pozostaje analogiczne jak w trybie JOINT.

Jeżeli zadany punkt jest poza obszarem osiągalnym lub wymaga przekroczenia limitu osi, polecenie nie jest wykonywane i może zostać zasygnalizowany błąd.

---

# 12. KINEMATYKA

## 12.1. Kinematyka prosta

Dla dwóch ramion SCARA położenie TCP w płaszczyźnie XY wyznaczane jest z zależności:

`X = L1·cos(θ1) + L2·cos(θ1 + θ2)`

`Y = L1·sin(θ1) + L2·sin(θ1 + θ2)`

oraz:

`Z = położenie osi Z`

gdzie:

- `L1` – długość pierwszego członu,
- `L2` – długość drugiego członu,
- `θ1` – kąt ARM1,
- `θ2` – kąt ARM2.

W aktualnej konfiguracji:

- `L1 = 91,61 mm`,
- `L2 = 97,528 mm`.

## 12.2. Kinematyka odwrotna

W trybie TOOL zadawana jest pozycja `(X,Y)`, a program oblicza kąty `θ1` i `θ2`.

Najpierw obliczana jest zależność:

`cos(θ2) = (X² + Y² − L1² − L2²) / (2·L1·L2)`

Jeżeli wynik znajduje się poza zakresem `−1...1`, punkt leży poza geometrycznym obszarem pracy.

Następnie wyznaczane są kąty przegubów. Dla typowego robota dwuprzegubowego istnieją dwie konfiguracje geometryczne, odpowiadające położeniu „łokcia” po dwóch stronach.

Aktualny firmware wykorzystuje jedną z tych konfiguracji (`ELBOW_UP`).

Po obliczeniu kątów sprawdzane są również programowe ograniczenia zakresów ARM1 i ARM2.

---

# 13. POZYCJA HOME I HOMING

Aktualny robot nie wykonuje automatycznego homingu.

Pozycję HOME należy ustawić ręcznie przed włączeniem zasilania lub resetem ESP32.

Firmware przyjmuje następujące wartości startowe:

| Oś | Pozycja HOME |
|---|---:|
| ARM1 | 0° |
| ARM2 | 0° |
| Z | 0 mm |
| Obrót chwytaka | 90° |
| Chwytak | 30° |

Po starcie licznik kroków każdej osi zostaje ustawiony na pozycję odpowiadającą HOME.

Jeżeli mechanika nie została rzeczywiście ustawiona w tej pozycji, wszystkie późniejsze obliczenia położenia będą obarczone błędem.

Automatyczny homing z wykorzystaniem krańcówek jest przewidywany jako możliwe przyszłe rozszerzenie.

---

# 14. FUNKCJA TEACH

Przycisk TEACH na płytce umożliwia zapis aktualnej pozycji robota.

TEACH działa tylko:

- w trybie MANUAL,
- przy zatrzymanych osiach,
- gdy E-STOP nie jest aktywny.

## 14.1. Krótkie naciśnięcie

Zapisuje kolejny punkt programu.

Każdy punkt zawiera:

- pozycję ARM1,
- pozycję ARM2,
- pozycję Z,
- pozycję serwa obrotu chwytaka,
- pozycję serwa chwytaka,
- czas postoju `dwellMs`.

Maksymalna liczba punktów wynosi 20.

## 14.2. Długie naciśnięcie

Przytrzymanie przycisku przez około 1,8 s usuwa cały zapisany program.

## 14.3. Pamięć

Program jest przechowywany w pamięci NVS ESP32. Dzięki temu nie jest tracony po wyłączeniu zasilania.

---

# 15. TRYB AUTO

Przycisk MODE przełącza pracę pomiędzy MANUAL i AUTO.

Zmiana trybu jest możliwa tylko przy zatrzymanych osiach.

W AUTO pad nie służy do bezpośredniego sterowania osiami.

Przycisk START realizuje funkcję:

- IDLE → START,
- RUN → PAUSE,
- PAUSED → RESUME.

AUTO odtwarza punkty zapisane wcześniej funkcją TEACH.

---

# 16. PRZEBIEG CYKLU AUTO

Dla każdego punktu programu wykonywane są następujące działania:

1. ustawienie pozycji docelowych serwomechanizmów,
2. wyznaczenie odległości do przejechania przez ARM1, ARM2 i Z,
3. dobranie prędkości osi,
4. rozpoczęcie ruchu PTP,
5. oczekiwanie na zakończenie ruchu wszystkich osi,
6. odczekanie zadanego czasu postoju,
7. przejście do kolejnego punktu.

W aktualnej konfiguracji program pracuje domyślnie w pętli.

## 16.1. Typ ruchu

Obecna implementacja AUTO realizuje ruch PTP (Point To Point).

Oznacza to, że synchronizowane są czasy przejazdu osi, ale tor TCP pomiędzy punktami nie musi być linią prostą.

Interpolacja liniowa LIN jest przewidywana jako możliwe przyszłe rozszerzenie.

---

# 17. REGULACJA PRĘDKOŚCI W AUTO

W gałęzi `dev` dostępna jest regulacja prędkości całego ruchu w trybie AUTO.

| D-pad | Funkcja |
|---|---|
| góra | +10% |
| dół | −10% |
| lewo | powrót do 100% |

Zakres regulacji:

`50% ... 250%`

Override skaluje bazowe prędkości wszystkich trzech osi: ARM1, ARM2 i Z. Przy 100% wartości bazowe wynoszą odpowiednio 20°/s, 20°/s i 3,0 mm/s.

Zmiana prędkości zaczyna obowiązywać od kolejnego ruchu PTP. Bieżący ruch nie jest przeliczany w locie.

---

# 18. ZABEZPIECZENIA PROGRAMOWE

Firmware zawiera kilka warstw zabezpieczeń i kontroli poprawności danych.

## 18.1. Limity pozycji

Polecenia ruchu są ograniczane do zakresów:

- ARM1: −105° ... +105°,
- ARM2: −125° ... +125°,
- Z: 0 ... 300 mm.

## 18.2. Częstotliwość STEP i prędkość

Aktualny firmware nie stosuje dodatkowych twardych górnych limitów częstotliwości STEP. Częstotliwość STEP wynika z zadanej prędkości osi, przełożenia, mikrokroku oraz override AUTO.

W MANUAL prędkość jest ograniczana do skonfigurowanych prędkości JOG, natomiast w AUTO do bazowych prędkości AUTO pomnożonych przez override 50...250%. Przyspieszenia są realizowane przez FastAccelStepper.

## 18.3. Walidacja wartości numerycznych

Przed przeliczeniami i wydaniem części poleceń ruchu sprawdzane są wartości typu `NaN` i `Inf`. W przypadku wykrycia błędu firmware nie przekazuje nieprawidłowej pozycji do napędów, może zsynchronizować pozycję z licznikami kroków i zgłasza błąd przez Serial/OLED.

## 18.4. Walidacja programu TEACH/NVS

Podczas odczytu programu z NVS sprawdzany jest rozmiar danych oraz poprawność zapisanych punktów. Nieprawidłowy program, np. zawierający `NaN`, `Inf` lub pozycję poza zakresem osi, jest odrzucany i czyszczony.

## 18.5. Timeout pada

W MANUAL brak aktualnych danych z kontrolera przez określony czas powoduje zatrzymanie ruchu i rozbrojenie sterowania.

## 18.6. Neutralne uzbrojenie pada

Po połączeniu kontrolera wymagane jest neutralne położenie elementów sterujących przez około 300 ms przed uzbrojeniem ruchu.

## 18.7. Utrata kontrolera w AUTO

Rozłączenie kontrolera podczas aktywnego cyklu AUTO powoduje przejście programu w PAUSE.

## 18.8. E-STOP

E-STOP zatrzaskuje stan awaryjny do czasu restartu sterownika. Programowo zatrzymywane są generatory kroków, AUTO przechodzi w FAULT, a sterowanie ręczne pozostaje zablokowane.

---

# 19. PROCEDURA MONTAŻU ELEKTRONIKI

1. Sprawdzić PCB pod kątem zwarć, uszkodzeń ścieżek i jakości lutowania.
2. Zweryfikować polaryzację kondensatorów elektrolitycznych i diod.
3. Sprawdzić orientację tranzystorów, układów scalonych i sterowników A4988.
4. Zamontować ESP32 na przewidzianych złączach goldpin.
5. Przed podłączeniem ESP32 i serw ustawić napięcie LM2596 na 5,0 V.
6. Podłączyć przewody silników, serw i elementów panelu zgodnie ze schematem.
7. Uporządkować przewody tak, aby nie kolidowały z ruchomymi częściami.
8. Zapewnić luz przewodów w miejscach ruchu.
9. Zapewnić wentylację A4988 oraz elementów wydzielających ciepło.
10. Sprawdzić działanie E-STOP przed testami ruchu.

---

# 20. PROCEDURA URUCHOMIENIA

Przed pierwszym uruchomieniem:

1. sprawdzić wszystkie połączenia mechaniczne,
2. sprawdzić naciąg pasków,
3. sprawdzić prowadzenie przewodów,
4. sprawdzić poprawność zasilania,
5. ustawić LM2596 na 5,0 V,
6. sprawdzić ustawienie prądów A4988,
7. upewnić się, że obszar pracy robota jest wolny,
8. ręcznie ustawić robot w pozycji HOME,
9. włączyć zasilanie,
10. obserwować diody sygnalizacyjne i komunikaty Serial,
11. połączyć kontroler Bluetooth,
12. pozostawić analogi i przyciski w neutralnym położeniu do czasu uzbrojenia,
13. wykonać krótkie testy pojedynczych osi przy małych wychyleniach analogów,
14. sprawdzić kierunki ruchu,
15. sprawdzić działanie E-STOP,
16. dopiero po poprawnym wykonaniu powyższych testów przejść do pełnego zakresu pracy.

---

# 21. TESTY ODBIORCZE

Zamiast ograniczać testy do stwierdzenia „działa poprawnie”, zaleca się zapisywanie wyników pomiarowych.

## 21.1. Kontrola PCB

**Kryterium:** brak zwarć, zimnych lutów, błędnej orientacji i uszkodzeń.

## 21.2. Kontrola napięcia 5 V

**Kryterium:** napięcie LM2596 ustawione na 5,0 V przed podłączeniem odbiorników wymagających tego napięcia.

## 21.3. Test ARM1

Zadać ruch np. o 30°, 60° i 90° w obu kierunkach.

**Sprawdzić:**

- kierunek,
- płynność,
- brak gubienia kroków,
- zgodność kąta rzeczywistego z zadanym.

## 21.4. Test ARM2

Analogicznie jak dla ARM1.

## 21.5. Test osi Z

Wykonać przejazdy kontrolne np. 5 mm, 10 mm i 20 mm.

Pomiar wykonać suwmiarką lub czujnikiem zegarowym.

## 21.6. Test chwytaka

Sprawdzić:

- pełne otwarcie,
- pełne zamknięcie,
- brak mechanicznego blokowania,
- brak nadmiernego poboru prądu przy dojeździe do ograniczeń.

## 21.7. Test TEACH

Zapisać kilka punktów, wyłączyć zasilanie, uruchomić ponownie i zweryfikować obecność programu.

## 21.8. Test AUTO

Zapisać minimum 5 punktów i uruchomić wielokrotne odtwarzanie.

Sprawdzić:

- osiąganie wszystkich punktów,
- poprawną obsługę serw,
- czasy postoju,
- działanie START/PAUSE/RESUME,
- poprawne przejście do kolejnego cyklu.

## 21.9. Test utraty kontrolera

### MANUAL

Rozłączenie pada powinno zatrzymać sterowanie.

### AUTO

Utrata kontrolera podczas aktywnego cyklu powinna przełączyć program w PAUSE.

## 21.10. Test E-STOP

Po aktywacji E-STOP:

- wszystkie osie powinny zostać zatrzymane,
- stan AUTO powinien przejść w FAULT,
- dalsza praca powinna być niemożliwa do czasu restartu.

## 21.11. Test powtarzalności

Wybrać minimum trzy punkty w przestrzeni roboczej.

Dla każdego wykonać co najmniej 20 dojazdów i zmierzyć rozrzut pozycji TCP.

Na podstawie tych pomiarów można dopiero wpisać rzeczywistą powtarzalność robota.

## 21.12. Test długotrwały

Zaleca się wykonanie co najmniej 30-minutowej pracy cyklicznej.

Należy monitorować:

- temperaturę A4988,
- temperaturę silników,
- temperaturę LM2596,
- stabilność Bluetooth,
- ewentualne gubienie kroków,
- samoczynne resety ESP32.

---

# 22. BEZPIECZEŃSTWO

Podczas pracy nie wolno:

- wkładać rąk w obszar pracy robota,
- zatrzymywać ramienia ręką,
- dotykać poruszających się pasków,
- pracować z uszkodzonymi przewodami,
- podłączać i odłączać silników krokowych przy załączonym zasilaniu,
- pozostawiać robota bez nadzoru podczas testów,
- uruchamiać pełnej prędkości przed zakończeniem testów pojedynczych osi.

Przed pracami serwisowymi należy odłączyć zasilanie.

Ze względu na edukacyjny charakter urządzenia wszystkie testy powinny być prowadzone pod nadzorem osoby znającej budowę stanowiska.

---

# 23. KONSERWACJA

Okresowo należy kontrolować:

- naciąg pasków,
- stan kół pasowych,
- stan łożysk,
- stan prowadnic,
- dokręcenie śrub,
- stan elementów drukowanych 3D,
- prowadzenie przewodów,
- temperaturę silników,
- temperaturę A4988,
- stabilność połączeń złączowych.

Szczególną uwagę należy zwracać na układ napędowy drugiego członu, ponieważ luz paska bezpośrednio wpływa na dokładność i powtarzalność robota.

---

# 24. MOŻLIWOŚCI ROZBUDOWY

Projekt może zostać rozwinięty o:

- automatyczny homing z wykorzystaniem krańcówek,
- interpolację liniową LIN w przestrzeni TCP,
- system wizyjny,
- kamerę do rozpoznawania obiektów,
- czujnik odległości,
- wykrywanie obecności detalu,
- elektromagnes,
- przyssawkę podciśnieniową,
- marker,
- dozownik,
- narzędzie pomiarowe,
- interfejs PC do edycji programów,
- zapis większej liczby programów,
- wybór programu z poziomu panelu,
- raportowanie pozycji i błędów przez Wi-Fi.

---

# 25. PRZYKŁADOWA SEKWENCJA PICK AND PLACE

Przykładowa sekwencja może wyglądać następująco:

`START → pozycja bazowa → przejazd nad detal → Z w dół → zamknięcie chwytaka → Z w górę → przejazd nad miejsce odkładania → Z w dół → otwarcie chwytaka → Z w górę → powrót → STOP`

Sekwencję można zapisać za pomocą funkcji TEACH, a następnie odtwarzać w trybie AUTO.

---

# 26. ZALEŻNOŚĆ PARAMETRÓW MECHANICZNYCH I PROGRAMOWYCH

Zmiana konstrukcji mechanicznej może wymagać modyfikacji firmware.

Przykładowo:

`zmiana długości ramienia → zmiana parametrów kinematyki → zmiana obliczanych kątów → zmiana położenia TCP`

Podobnie:

`zmiana przełożenia → zmiana liczby kroków/stopień → błędna pozycja osi przy starych parametrach`

Dlatego po każdej modyfikacji:

- długości ramion,
- kół pasowych,
- przełożeń,
- śruby osi Z,
- mikrokroku,

należy sprawdzić i w razie potrzeby zaktualizować parametry programu.

---

# 27. WERSJONOWANIE DOKUMENTACJI

Dokumentacja techniczna powinna zawsze wskazywać wersję firmware lub commit repozytorium, do którego się odnosi.

Jest to szczególnie ważne, ponieważ w trakcie rozwoju projektu zmieniały się m.in.:

- prędkości osi,
- przyspieszenia,
- zachowanie przycisków MODE i TEACH,
- obsługa utraty połączenia z padem,
- parametry AUTO,
- zabezpieczenia przed niekontrolowanym ruchem.

Przed wydrukowaniem dokumentacji zaleca się wpisanie:

- numeru rewizji PCB,
- nazwy gałęzi,
- hash commita,
- daty wersji,
- autora dokumentacji.

---

# 28. POCHODZENIE ELEMENTÓW PROJEKTU

Konstrukcja mechaniczna korzysta z rozwiązań i modeli projektu bazowego PyBot, natomiast układ sterowania, płytka PCB, konfiguracja ESP32 i aktualny firmware są rozwijane w ramach niniejszego projektu.

Przed publiczną dystrybucją kompletu materiałów należy zweryfikować warunki licencyjne modeli źródłowych oraz dodać do repozytorium odpowiednie informacje o licencjach i autorach.

---

# 29. PODSUMOWANIE

Projekt „Robotyka bez granic” stanowi kompletne edukacyjne stanowisko mechatroniczne łączące mechanikę, druk 3D, elektronikę, napędy, programowanie mikrokontrolerów, kinematykę robotów oraz zagadnienia automatyzacji.

Aktualna wersja robota umożliwia:

- sterowanie bezprzewodowe,
- ręczne prowadzenie osi w trybie JOINT,
- sterowanie TCP w trybie TOOL,
- zapisywanie punktów TEACH,
- automatyczne odtwarzanie programu PTP,
- regulację prędkości ARM1, ARM2 i Z w AUTO,
- bieżący podgląd stanu na wyświetlaczu OLED,
- trwałe przechowywanie programu w pamięci ESP32,
- zatrzymanie awaryjne oraz dodatkowe zabezpieczenia programowe.

Najważniejszymi dalszymi kierunkami rozwoju są automatyczny homing, interpolacja LIN, pomiar rzeczywistej powtarzalności i udźwigu oraz dalsza rozbudowa interfejsu operatora.

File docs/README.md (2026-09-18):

# Dokumentacja projektu SCARA

Ten katalog zawiera dokumentację eksploatacyjną i techniczną robota SCARA.

## Najważniejsze pliki

- [`INSTRUKCJA_OBSLUGI_PL.md`](INSTRUKCJA_OBSLUGI_PL.md) – instrukcja uruchomienia i obsługi robota.
- [`AUTO_TEACH.md`](AUTO_TEACH.md) – skrócony opis trybów MANUAL, TOOL, TEACH i AUTO.
- [`DOKUMENTACJA_TECHNICZNA_PL.md`](DOKUMENTACJA_TECHNICZNA_PL.md) – pełna dokumentacja techniczna w języku polskim.
- [`DOKUMENTACJA_TECHNICZNA_UA.md`](DOKUMENTACJA_TECHNICZNA_UA.md) – pełna dokumentacja techniczna w języku ukraińskim.
- `DOKUMENTACJA_TECHNICZNA_PL.docx` i `DOKUMENTACJA_TECHNICZNA_UA.docx` – wersje Word przygotowane do druku i dalszej edycji.

## Aktualne zachowanie firmware

Aktualna gałąź `main` zawiera m.in.:

- ręczne ustawianie ARM1 i ARM2 na `0°` przed startem,
- startową procedurę ręcznego HOME osi Z z pada,
- potwierdzenie `Z = 0` przez jednoczesne naciśnięcie `A+B`,
- blokadę normalnej pracy do zatwierdzenia HOME Z,
- logo na OLED przez 5 s po uruchomieniu,
- tryby MANUAL JOINT, MANUAL TOOL i AUTO,
- zapis maksymalnie 20 punktów TEACH do NVS,
- automatyczne odtwarzanie PTP,
- regulację prędkości AUTO 50–250%,
- serwo 2 startujące z `90°` i ograniczone programowo do `90–180°`,
- komentarze w kodzie w językach polskim, angielskim i ukraińskim.

## Ważna uwaga o pozycji osi

Robot nie posiada enkoderów położenia głównych osi. Pozycja jest wyznaczana na podstawie liczników kroków silników. Jeżeli silnik zgubi kroki albo mechanika zostanie przestawiona ręcznie po uruchomieniu, sterownik nie wykryje automatycznie tej różnicy.

Z tego powodu po każdym restarcie należy:

1. ustawić ARM1 i ARM2 w pozycji `0°`,
2. wykonać procedurę HOME osi Z,
3. dopiero potem przejść do TEACH lub AUTO.

## Pliki źródłowe elektroniki

Dokumentacja płytki znajduje się w katalogu [`../PCB`](../PCB), a edytowalne pliki EasyEDA w [`../PCB/EasyEDA`](../PCB/EasyEDA).

## Pliki mechaniczne

Modele do druku 3D znajdują się w [`../3DPrinting`](../3DPrinting). Informacje o pochodzeniu modeli i licencjach są opisane w [`../3DPrinting/README.md`](../3DPrinting/README.md) oraz [`../THIRD_PARTY_NOTICES.md`](../THIRD_PARTY_NOTICES.md).

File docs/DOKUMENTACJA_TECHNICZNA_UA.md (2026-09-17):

# ТЕХНІЧНА ДОКУМЕНТАЦІЯ
## РОБОТИЗОВАНА РУКА SCARA
### Проєкт «Робототехніка без кордонів»

**Тип пристрою:** навчальна роботизована рука SCARA 3 DOF + захват 2 DOF  
**Контролер:** ESP32 D1 Mini / WeMos D1 Mini ESP32  
**Керування:** Bluetooth-контролер + кнопки на платі  
**Програмне забезпечення:** C++ / Arduino Framework / PlatformIO  
**Репозиторій:** `Attiny2313/SCARA-Robot-Controler-BT`  
**Гілка, якій відповідає цей опис:** `dev`  
**Базовий commit firmware/config:** `3dcf2272da6c95ba952772bd750d242ef21eb560`  

> Документ описує фактичну версію проєкту, що розробляється в репозиторії. Дані, що походять із базового проєкту PyBot, відокремлені від параметрів, які випливають із поточної конструкції та керуючої програми.

---

# 1. МЕТА ПРОЄКТУ

Метою проєкту є виготовлення, запуск і програмування навчального робота типу SCARA (Selective Compliance Assembly Robot Arm), призначеного для вивчення питань механіки, електроніки, автоматики, робототехніки, програмування та технологій 3D-друку.

Робот дає змогу:

- вручну керувати окремими осями,
- керувати положенням робочого органу в декартовій системі координат,
- керувати захватом,
- зберігати точки методом TEACH,
- автоматично відтворювати збережену послідовність рухів,
- виконувати завдання типу Pick and Place,
- надалі розширювати систему додатковими датчиками, системою машинного зору та іншими робочими інструментами.

Проєкт має навчальний та експериментальний характер. Він не є промисловим пристроєм або сертифікованим роботом, призначеним для роботи у виробничому середовищі.

---

# 2. ХАРАКТЕРИСТИКА РОБОТА

Робот є маніпулятором типу SCARA, основна виконавча частина якого складається з:

- обертальної осі ARM1,
- обертальної осі ARM2,
- лінійної вертикальної осі Z,
- сервомеханізму обертання захвата,
- сервомеханізму відкривання та закривання захвата.

За рух трьох основних осей відповідають крокові двигуни NEMA 17. Обертання захвата та його відкривання реалізуються сервомеханізмами.

Механічна конструкція базується на рішеннях проєкту PyBot і використовує елементи, виготовлені методом 3D-друку, а також стандартні механічні компоненти, що застосовуються, зокрема, у 3D-принтерах.

Керування реалізує мікроконтролер ESP32, який працює разом із спеціальною платою PCB. ESP32 зв’язується з бездротовим контролером через Bluetooth і самостійно реалізує логіку керування, кінематику, генерацію траєкторії PTP, обслуговування TEACH/AUTO та програмні засоби захисту.

Комп’ютер не потрібен для нормальної роботи робота. Він використовується для програмування, оновлення firmware та діагностики через послідовний порт.

---

# 3. ТЕХНІЧНІ ПАРАМЕТРИ

## 3.1. Параметри конструкції та керування

| Параметр | Значення |
|---|---:|
| Тип робота | SCARA |
| Кількість основних осей | 3 |
| Робочі осі | ARM1, ARM2, Z |
| Додаткові осі захвата | 2 |
| Основні двигуни | 3 × NEMA 17 |
| Кут повного кроку двигуна | 1,8° |
| Кількість повних кроків на оберт | 200 |
| Мікрокрок | 1/16 |
| Сервомеханізми | 2 × класу SG90/MG90/MG92R |
| Основний контролер | ESP32 D1 Mini |
| Драйвери двигунів | A4988 |
| Середовище програмування | PlatformIO / Visual Studio Code |
| Framework | Arduino |
| Мова програми | C++ |
| Зв’язок із геймпадом | Bluetooth / Bluepad32 |

## 3.2. Параметри, що використовуються поточним firmware

| Параметр | Значення |
|---|---:|
| Довжина ланки ARM1 | 91,61 мм |
| Довжина ланки ARM2 | 97,528 мм |
| Передатне відношення ARM1 | 4,5 |
| Передатне відношення ARM2 | 7,280 |
| Крок гвинта осі Z | 2,0 мм/об. |
| Передатне відношення Z | 1,0 |
| Програмний діапазон ARM1 | −105° ... +105° |
| Програмний діапазон ARM2 | −125° ... +125° |
| Програмний діапазон Z | 0 ... 300 мм |
| Діапазон обертання захвата | 0 ... 180° |
| Діапазон серво захвата | 15 ... 95° |
| Ручна швидкість ARM1 | 25°/с |
| Ручна швидкість ARM2 | 25°/с |
| Ручна швидкість Z | 3,0 мм/с |
| Швидкість TCP у режимі TOOL | 20 мм/с |
| Базова швидкість AUTO ARM1 | 20°/с |
| Базова швидкість AUTO ARM2 | 20°/с |
| Базова швидкість AUTO Z | 3,0 мм/с |
| Override швидкості AUTO | 50...250% для ARM1, ARM2 і Z |
| Прискорення ARM1 | 12000 STEP/с² |
| Прискорення ARM2 | 5000 STEP/с² |
| Прискорення Z | 6000 STEP/с² |
| Кількість точок програми TEACH | макс. 20 |

## 3.3. Параметри, що потребують вимірювання реального екземпляра

Не слід без додаткових вимірювань приймати значення, заявлені для базового проєкту PyBot, як параметри готового робота.

Зокрема, потребують вимірювання:

- фактична маса робота,
- фактичний робочий простір,
- фактична повторюваність позиціонування,
- максимальна безпечна вантажопідйомність,
- максимальні практичні швидкості осей,
- точність позиціонування TCP.

До моменту проведення приймальних випробувань ці значення слід вважати такими, що підлягають визначенню.

---

# 4. МЕХАНІЧНА КОНСТРУКЦІЯ

## 4.1. Основа

Основа є несучим елементом усієї конструкції. До неї кріпляться, зокрема:

- напрямні осі Z,
- приводи,
- елементи пасових передач,
- керуюча електроніка,
- елементи захисту кабелів.

Основа повинна забезпечувати жорсткість конструкції та можливість стабільного встановлення робота на робочому місці.

## 4.2. Перша ланка руки – ARM1

Перша ланка з’єднує основу з центральним шарніром робота. Її рух змінює напрямок усього маніпулятора в площині XY.

Привід реалізований кроковим двигуном через пасову передачу.

## 4.3. Друга ланка руки – ARM2

Друга ланка з’єднує першу ланку з робочим органом. Разом з віссю ARM1 вона визначає положення TCP у площині XY.

Рух реалізується незалежним кроковим приводом через систему пасових передач.

## 4.4. Вертикальна вісь Z

Вісь Z забезпечує вертикальний рух робочого органу. Привід здійснюється за допомогою крокового двигуна та гвинта з кроком 2 мм/оберт.

Через велику кількість кроків на 1 мм руху та ризик пропуску кроків вісь Z працює зі значно нижчою швидкістю, ніж обертальні осі.

## 4.5. Захват

Захват оснащений двома сервомеханізмами:

- серво обертання інструмента,
- серво відкривання та закривання захвата.

Положення сервоприводів можуть зберігатися разом із точками програми TEACH.

---

# 5. СИСТЕМА ПРИВОДІВ

## 5.1. Крокові двигуни

Кожна з трьох основних осей використовує двигун NEMA 17 з кутом повного кроку 1,8°.

Повному оберту відповідає:

`360° / 1,8° = 200 кроків`

При використанні мікрокроку 1/16:

`200 × 16 = 3200 мікрокроків на оберт двигуна`

Додатково кількість робочих кроків залежить від передатного відношення конкретної осі.

Для осі Z, за кроку гвинта 2 мм/оберт і мікрокроку 1/16:

`3200 / 2 = 1600 кроків/мм`

Це значення використовується firmware для перерахунку положення осі Z.

## 5.2. Драйвери A4988

Драйвери A4988 відповідають за живлення та керування кроковими двигунами. Кожен драйвер отримує від ESP32 сигнали:

- STEP,
- DIR.

Необхідно правильно налаштувати струм драйверів відповідно до застосованих двигунів і способу охолодження.

Не можна підключати або відключати кроковий двигун при ввімкненому живленні драйвера.

---

# 6. ЕЛЕКТРИЧНА ТА ЕЛЕКТРОННА СИСТЕМА

## 6.1. Основні елементи

Електронна система містить:

- ESP32 D1 Mini,
- 3 драйвери A4988,
- перетворювач LM2596,
- роз’єми двигунів,
- роз’єми сервомеханізмів,
- кнопки TEACH і MODE,
- коло E-STOP,
- сигнальні світлодіоди,
- OLED-дисплей SSD1306 128×64 I2C,
- роз’єми кінцевих вимикачів,
- пасивні та захисні елементи.

Документація плати PCB знаходиться в каталозі `PCB` репозиторію.

## 6.2. Призначення входів і виходів ESP32

| Функція | GPIO |
|---|---:|
| STEP ARM1 | 13 |
| DIR ARM1 | 26 |
| STEP ARM2 | 23 |
| DIR ARM2 | 14 |
| STEP Z | 18 |
| DIR Z | 19 |
| Servo ROTATE | 27 |
| Servo GRIP | 32 |
| TEACH | 25 |
| MODE | 33 |
| E-STOP | 39 |
| Кінцевий вимикач Z | 34 |
| Кінцевий вимикач ARM1 | 35 |
| Кінцевий вимикач ARM2 | 36 |
| LED Bluetooth | 4 |
| LED ERROR | 16 |
| LED STATUS | 17 |
| I2C SDA (OLED) | 21 |
| I2C SCL (OLED) | 22 |

## 6.3. Кінцеві вимикачі

Плата має входи для кінцевих вимикачів осей ARM1, ARM2 і Z.

У поточній версії firmware кінцеві вимикачі не реалізують автоматичний homing. Входи збережені апаратно для майбутнього розширення.

## 6.4. E-STOP

E-STOP є елементом безпеки системи.

Після його активації firmware:

- негайно зупиняє генерацію кроків,
- блокує ручне керування,
- переводить програму AUTO у стан FAULT,
- сигналізує про помилку,
- вимагає перезапуску контролера перед повторною роботою.

Система повинна бути виконана так, щоб E-STOP не покладався виключно на програмне забезпечення, а додатково обмежував можливість подальшого живлення або активації приводів відповідно до концепції керуючої плати.

## 6.5. OLED-дисплей

Контролер підтримує OLED-дисплей SSD1306 128×64, підключений через I2C. Шина використовує GPIO21 як SDA і GPIO22 як SCL.

Під час ініціалізації firmware автоматично перевіряє адреси `0x3C` і `0x3D`. Відсутність дисплея не блокує роботу робота — інформація про проблему передається через Serial.

Під час роботи OLED показує, зокрема:

- режим MANUAL/AUTO і стан програми,
- стан Bluetooth-з’єднання,
- кількість збережених точок TEACH,
- override швидкості в AUTO,
- фактичні положення ARM1, ARM2 і Z,
- положення TCP X/Y або номер поточної точки програми,
- стани помилок, зокрема `E-STOP` і `NUM ERR`.

---

# 7. АРХІТЕКТУРА КЕРУВАННЯ

Фактичний потік керування можна подати так:

`Bluetooth-геймпад → Bluepad32 → ESP32 → логіка керування → кінематика / AUTO → FastAccelStepper → A4988 → двигуни NEMA17`

Паралельно:

`ESP32 → ESP32Servo → серво обертання + серво захвата`

ESP32 одночасно виконує функції:

- приймача команд,
- контролера осей,
- контролера сервоприводів,
- модуля кінематики,
- генератора послідовності AUTO,
- пам’яті програми TEACH,
- програмного модуля безпеки,
- діагностичного модуля.

---

# 8. ПРОГРАМНЕ ЗАБЕЗПЕЧЕННЯ

## 8.1. Середовище

Керуючу програму підготовлено мовою C++ з використанням:

- Arduino Framework,
- PlatformIO,
- Visual Studio Code.

## 8.2. Основні бібліотеки

### Bluepad32

Бібліотека відповідає за обслуговування Bluetooth-контролерів.

### FastAccelStepper

Бібліотека генерує сигнали STEP для трьох осей і дає змогу задавати швидкість, прискорення та положення.

### ESP32Servo

Бібліотека керує сервомеханізмами захвата.

### Preferences

Бібліотека обслуговує пам’ять NVS ESP32. У пам’яті зберігається програма TEACH, завдяки чому точки залишаються доступними після вимкнення живлення.

### Adafruit GFX / Adafruit SSD1306

Бібліотеки відповідають за роботу OLED-дисплея SSD1306 128×64, відображення стану робота та базову діагностику.

---

# 9. РЕЖИМИ РОБОТИ

Контролер використовує два незалежні рівні режимів.

## 9.1. Основний режим роботи

- `MANUAL`
- `AUTO`

## 9.2. Режим ручного керування

У режимі MANUAL доступні:

- `JOINT`
- `TOOL`

Таким чином, вибір JOINT/TOOL не є тим самим, що вибір MANUAL/AUTO.

---

# 10. РУЧНЕ КЕРУВАННЯ – JOINT

У режимі JOINT оператор безпосередньо керує окремими осями робота.

Поточне призначення органів геймпада:

| Елемент контролера | Функція |
|---|---|
| Лівий аналог X | ARM1 |
| Лівий аналог Y | ARM2 |
| Правий аналог Y | Z |
| Правий аналог X | обертання захвата |
| A / B | відкривання / закривання захвата |
| START | JOINT / TOOL |

Значення з аналогових стиків нормалізуються та мають мертву зону, щоб невеликі відхилення стика не спричиняли рух робота.

Після підключення контролера робот не озброюється одразу. Потрібно приблизно 300 мс нейтрального положення всіх органів керування. Це запобігає неконтрольованому руху відразу після спарювання геймпада.

---

# 11. РУЧНЕ КЕРУВАННЯ – TOOL

У режимі TOOL оператор не керує безпосередньо кутами ARM1 і ARM2.

Лівий аналог задає рух робочого органу в площині XY, а програма обчислює необхідні кути плечей за допомогою оберненої кінематики.

Керування віссю Z та захватом залишається аналогічним до режиму JOINT.

Якщо задана точка знаходиться поза досяжною областю або потребує перевищення межі осі, команда не виконується і може бути сигналізована помилка.

---

# 12. КІНЕМАТИКА

## 12.1. Пряма кінематика

Для двох плечей SCARA положення TCP у площині XY визначається залежностями:

`X = L1·cos(θ1) + L2·cos(θ1 + θ2)`

`Y = L1·sin(θ1) + L2·sin(θ1 + θ2)`

та:

`Z = положення осі Z`

де:

- `L1` – довжина першої ланки,
- `L2` – довжина другої ланки,
- `θ1` – кут ARM1,
- `θ2` – кут ARM2.

У поточній конфігурації:

- `L1 = 91,61 мм`,
- `L2 = 97,528 мм`.

## 12.2. Обернена кінематика

У режимі TOOL задається положення `(X,Y)`, а програма обчислює кути `θ1` і `θ2`.

Спочатку обчислюється залежність:

`cos(θ2) = (X² + Y² − L1² − L2²) / (2·L1·L2)`

Якщо результат виходить за межі `−1...1`, точка знаходиться поза геометричною робочою областю.

Потім визначаються кути шарнірів. Для типового двошарнірного робота існують дві геометричні конфігурації, що відповідають положенню «ліктя» з двох боків.

Поточний firmware використовує одну з цих конфігурацій (`ELBOW_UP`).

Після обчислення кутів також перевіряються програмні обмеження діапазонів ARM1 і ARM2.

---

# 13. ПОЛОЖЕННЯ HOME І HOMING

Поточний робот не виконує автоматичний homing.

Положення HOME необхідно встановити вручну перед увімкненням живлення або скиданням ESP32.

Firmware приймає такі стартові значення:

| Вісь | Положення HOME |
|---|---:|
| ARM1 | 0° |
| ARM2 | 0° |
| Z | 0 мм |
| Обертання захвата | 90° |
| Захват | 30° |

Після запуску лічильник кроків кожної осі встановлюється в положення, що відповідає HOME.

Якщо механіка фактично не була встановлена в це положення, усі подальші обчислення положення міститимуть помилку.

Автоматичний homing із використанням кінцевих вимикачів передбачений як можливе майбутнє розширення.

---

# 14. ФУНКЦІЯ TEACH

Кнопка TEACH на платі дає змогу зберегти поточне положення робота.

TEACH працює лише:

- у режимі MANUAL,
- при зупинених осях,
- коли E-STOP не активний.

## 14.1. Коротке натискання

Зберігає наступну точку програми.

Кожна точка містить:

- положення ARM1,
- положення ARM2,
- положення Z,
- положення серво обертання захвата,
- положення серво захвата,
- час паузи `dwellMs`.

Максимальна кількість точок становить 20.

## 14.2. Довге натискання

Утримання кнопки приблизно 1,8 с видаляє всю збережену програму.

## 14.3. Пам’ять

Програма зберігається в пам’яті NVS ESP32. Завдяки цьому вона не втрачається після вимкнення живлення.

---

# 15. РЕЖИМ AUTO

Кнопка MODE перемикає роботу між MANUAL і AUTO.

Зміна режиму можлива лише при зупинених осях.

У AUTO геймпад не використовується для безпосереднього керування осями.

Кнопка START реалізує функції:

- IDLE → START,
- RUN → PAUSE,
- PAUSED → RESUME.

AUTO відтворює точки, раніше збережені функцією TEACH.

---

# 16. ПЕРЕБІГ ЦИКЛУ AUTO

Для кожної точки програми виконуються такі дії:

1. встановлення цільових положень сервомеханізмів,
2. визначення відстані, яку мають пройти ARM1, ARM2 і Z,
3. вибір швидкостей осей,
4. початок руху PTP,
5. очікування завершення руху всіх осей,
6. очікування заданого часу паузи,
7. перехід до наступної точки.

У поточній конфігурації програма за замовчуванням працює циклічно.

## 16.1. Тип руху

Поточна реалізація AUTO виконує рух PTP (Point To Point).

Це означає, що синхронізуються часи переміщення осей, але траєкторія TCP між точками не обов’язково є прямою лінією.

Лінійна інтерполяція LIN передбачена як можливе майбутнє розширення.

---

# 17. РЕГУЛЮВАННЯ ШВИДКОСТІ В AUTO

У гілці `dev` доступне регулювання швидкості всього руху в режимі AUTO.

| D-pad | Функція |
|---|---|
| вгору | +10% |
| вниз | −10% |
| вліво | повернення до 100% |

Діапазон регулювання:

`50% ... 250%`

Override масштабує базові швидкості всіх трьох осей: ARM1, ARM2 і Z. При 100% базові значення становлять відповідно 20°/с, 20°/с і 3,0 мм/с.

Зміна швидкості починає діяти з наступного руху PTP. Поточний рух не перераховується в реальному часі.

---

# 18. ПРОГРАМНІ ЗАСОБИ ЗАХИСТУ

Firmware містить кілька рівнів захисту та перевірки коректності даних.

## 18.1. Межі положення

Команди руху обмежуються діапазонами:

- ARM1: −105° ... +105°,
- ARM2: −125° ... +125°,
- Z: 0 ... 300 мм.

## 18.2. Частота STEP і швидкість

Поточний firmware не використовує додаткових жорстких верхніх обмежень частоти STEP. Частота STEP визначається заданою швидкістю осі, передатним відношенням, мікрокроком та override AUTO.

У MANUAL швидкість обмежується налаштованими швидкостями JOG, а в AUTO — базовими швидкостями AUTO, помноженими на override 50...250%. Прискорення реалізує FastAccelStepper.

## 18.3. Перевірка числових значень

Перед обчисленнями та частиною команд руху перевіряються значення типу `NaN` і `Inf`. У разі виявлення помилки firmware не передає некоректну позицію приводам, може синхронізувати позицію з лічильниками кроків і повідомляє про помилку через Serial/OLED.

## 18.4. Перевірка програми TEACH/NVS

Під час читання програми з NVS перевіряються розмір даних і коректність збережених точок. Некоректна програма, наприклад із `NaN`, `Inf` або позицією поза діапазоном осі, відхиляється та очищується.

## 18.5. Timeout геймпада

У MANUAL відсутність актуальних даних від контролера протягом визначеного часу спричиняє зупинку руху та роззброєння керування.

## 18.6. Нейтральне озброєння геймпада

Після підключення контролера необхідне нейтральне положення органів керування приблизно 300 мс перед активацією руху.

## 18.7. Втрата контролера в AUTO

Відключення контролера під час активного циклу AUTO переводить програму в PAUSE.

## 18.8. E-STOP

E-STOP фіксує аварійний стан до моменту перезапуску контролера. Програмно зупиняються генератори кроків, AUTO переходить у FAULT, а ручне керування залишається заблокованим.

---

# 19. ПРОЦЕДУРА МОНТАЖУ ЕЛЕКТРОНІКИ

1. Перевірити PCB на наявність коротких замикань, пошкоджень доріжок і якість пайки.
2. Перевірити полярність електролітичних конденсаторів і діодів.
3. Перевірити орієнтацію транзисторів, інтегральних схем і драйверів A4988.
4. Встановити ESP32 у передбачені роз’єми goldpin.
5. Перед підключенням ESP32 і сервоприводів встановити напругу LM2596 на 5,0 В.
6. Підключити проводи двигунів, сервоприводів і елементів панелі відповідно до схеми.
7. Упорядкувати проводи так, щоб вони не заважали рухомим частинам.
8. Забезпечити запас довжини проводів у місцях руху.
9. Забезпечити вентиляцію A4988 та елементів, що виділяють тепло.
10. Перевірити роботу E-STOP перед випробуваннями руху.

---

# 20. ПРОЦЕДУРА ЗАПУСКУ

Перед першим запуском:

1. перевірити всі механічні з’єднання,
2. перевірити натяг ременів,
3. перевірити прокладання проводів,
4. перевірити правильність живлення,
5. встановити LM2596 на 5,0 В,
6. перевірити налаштування струмів A4988,
7. переконатися, що робоча зона робота вільна,
8. вручну встановити робота в положення HOME,
9. увімкнути живлення,
10. спостерігати за сигнальними світлодіодами та повідомленнями Serial,
11. підключити Bluetooth-контролер,
12. залишити аналоги та кнопки в нейтральному положенні до моменту озброєння,
13. виконати короткі тести окремих осей при малих відхиленнях аналогів,
14. перевірити напрямки руху,
15. перевірити роботу E-STOP,
16. лише після успішного виконання наведених вище тестів перейти до повного діапазону роботи.

---

# 21. ПРИЙМАЛЬНІ ВИПРОБУВАННЯ

Замість обмеження тестів твердженням «працює правильно» рекомендується записувати результати вимірювань.

## 21.1. Контроль PCB

**Критерій:** відсутність коротких замикань, холодних пайок, неправильної орієнтації та пошкоджень.

## 21.2. Контроль напруги 5 В

**Критерій:** напруга LM2596 встановлена на 5,0 В перед підключенням споживачів, які потребують цієї напруги.

## 21.3. Тест ARM1

Задати рух, наприклад, на 30°, 60° і 90° в обох напрямках.

**Перевірити:**

- напрямок,
- плавність,
- відсутність пропусків кроків,
- відповідність фактичного кута заданому.

## 21.4. Тест ARM2

Аналогічно до ARM1.

## 21.5. Тест осі Z

Виконати контрольні переміщення, наприклад, 5 мм, 10 мм і 20 мм.

Вимірювання виконати штангенциркулем або індикатором годинникового типу.

## 21.6. Тест захвата

Перевірити:

- повне відкриття,
- повне закриття,
- відсутність механічного заклинювання,
- відсутність надмірного споживання струму при досягненні обмежень.

## 21.7. Тест TEACH

Зберегти кілька точок, вимкнути живлення, знову запустити систему та перевірити наявність програми.

## 21.8. Тест AUTO

Зберегти щонайменше 5 точок і запустити багаторазове відтворення.

Перевірити:

- досягнення всіх точок,
- правильну роботу сервоприводів,
- часи пауз,
- роботу START/PAUSE/RESUME,
- правильний перехід до наступного циклу.

## 21.9. Тест втрати контролера

### MANUAL

Відключення геймпада має зупинити керування.

### AUTO

Втрата контролера під час активного циклу повинна перевести програму в PAUSE.

## 21.10. Тест E-STOP

Після активації E-STOP:

- усі осі мають бути зупинені,
- стан AUTO має перейти в FAULT,
- подальша робота має бути неможливою до перезапуску.

## 21.11. Тест повторюваності

Вибрати щонайменше три точки в робочому просторі.

Для кожної виконати щонайменше 20 підходів і виміряти розкид положення TCP.

Лише на основі цих вимірювань можна вказати фактичну повторюваність робота.

## 21.12. Тривалий тест

Рекомендується провести щонайменше 30-хвилинну циклічну роботу.

Необхідно контролювати:

- температуру A4988,
- температуру двигунів,
- температуру LM2596,
- стабільність Bluetooth,
- можливі пропуски кроків,
- самовільні перезавантаження ESP32.

---

# 22. БЕЗПЕКА

Під час роботи заборонено:

- вводити руки в робочу зону робота,
- зупиняти плече рукою,
- торкатися рухомих ременів,
- працювати з пошкодженими проводами,
- підключати та відключати крокові двигуни при ввімкненому живленні,
- залишати робота без нагляду під час тестів,
- запускати повну швидкість до завершення тестів окремих осей.

Перед сервісними роботами необхідно відключити живлення.

Через навчальний характер пристрою всі тести повинні проводитися під наглядом особи, яка знає конструкцію стенда.

---

# 23. ТЕХНІЧНЕ ОБСЛУГОВУВАННЯ

Періодично необхідно контролювати:

- натяг ременів,
- стан шківів,
- стан підшипників,
- стан напрямних,
- затягування гвинтів,
- стан елементів, надрукованих на 3D-принтері,
- прокладання проводів,
- температуру двигунів,
- температуру A4988,
- стабільність з’єднань роз’ємів.

Особливу увагу слід приділяти приводу другої ланки, оскільки люфт ременя безпосередньо впливає на точність і повторюваність робота.

---

# 24. МОЖЛИВОСТІ РОЗШИРЕННЯ

Проєкт може бути розширений такими функціями:

- автоматичний homing із використанням кінцевих вимикачів,
- лінійна інтерполяція LIN у просторі TCP,
- система машинного зору,
- камера для розпізнавання об’єктів,
- датчик відстані,
- виявлення наявності деталі,
- електромагніт,
- вакуумна присоска,
- маркер,
- дозатор,
- вимірювальний інструмент,
- інтерфейс PC для редагування програм,
- зберігання більшої кількості програм,
- вибір програми з панелі,
- передавання положення та помилок через Wi-Fi.

---

# 25. ПРИКЛАД ПОСЛІДОВНОСТІ PICK AND PLACE

Приклад послідовності може виглядати так:

`START → базове положення → переміщення над деталлю → Z вниз → закриття захвата → Z вгору → переміщення над місцем укладання → Z вниз → відкриття захвата → Z вгору → повернення → STOP`

Послідовність можна зберегти за допомогою функції TEACH, а потім відтворювати в режимі AUTO.

---

# 26. ВЗАЄМОЗВ’ЯЗОК МЕХАНІЧНИХ І ПРОГРАМНИХ ПАРАМЕТРІВ

Зміна механічної конструкції може потребувати модифікації firmware.

Наприклад:

`зміна довжини плеча → зміна параметрів кінематики → зміна обчислюваних кутів → зміна положення TCP`

Аналогічно:

`зміна передатного відношення → зміна кількості кроків/градус → неправильне положення осі зі старими параметрами`

Тому після кожної модифікації:

- довжини плечей,
- шківів,
- передатних відношень,
- гвинта осі Z,
- мікрокроку,

необхідно перевірити та, за потреби, оновити параметри програми.

---

# 27. ВЕРСІОНУВАННЯ ДОКУМЕНТАЦІЇ

Технічна документація завжди повинна вказувати версію firmware або commit репозиторію, до якого вона належить.

Це особливо важливо, оскільки під час розвитку проєкту змінювалися, зокрема:

- швидкості осей,
- прискорення,
- поведінка кнопок MODE і TEACH,
- обслуговування втрати зв’язку з геймпадом,
- параметри AUTO,
- захист від неконтрольованого руху.

Перед друком документації рекомендується вказати:

- номер ревізії PCB,
- назву гілки,
- hash commit,
- дату версії,
- автора документації.

---

# 28. ПОХОДЖЕННЯ ЕЛЕМЕНТІВ ПРОЄКТУ

Механічна конструкція використовує рішення та моделі базового проєкту PyBot, тоді як система керування, плата PCB, конфігурація ESP32 і поточний firmware розробляються в межах цього проєкту.

Перед публічним розповсюдженням повного комплекту матеріалів необхідно перевірити ліцензійні умови вихідних моделей і додати до репозиторію відповідну інформацію про ліцензії та авторів.

---

# 29. ПІДСУМОК

Проєкт «Робототехніка без кордонів» є комплексним навчальним мехатронним стендом, що поєднує механіку, 3D-друк, електроніку, приводи, програмування мікроконтролерів, кінематику роботів та питання автоматизації.

Поточна версія робота дає змогу:

- бездротове керування,
- ручне керування осями в режимі JOINT,
- керування TCP у режимі TOOL,
- зберігання точок TEACH,
- автоматичне відтворення програми PTP,
- регулювання швидкості ARM1, ARM2 і Z в AUTO,
- поточне відображення стану на OLED-дисплеї,
- постійне зберігання програми в пам’яті ESP32,
- аварійну зупинку та додаткові програмні засоби захисту.

Найважливішими подальшими напрямами розвитку є автоматичний homing, інтерполяція LIN, вимірювання фактичної повторюваності та вантажопідйомності, а також подальший розвиток інтерфейсу оператора.

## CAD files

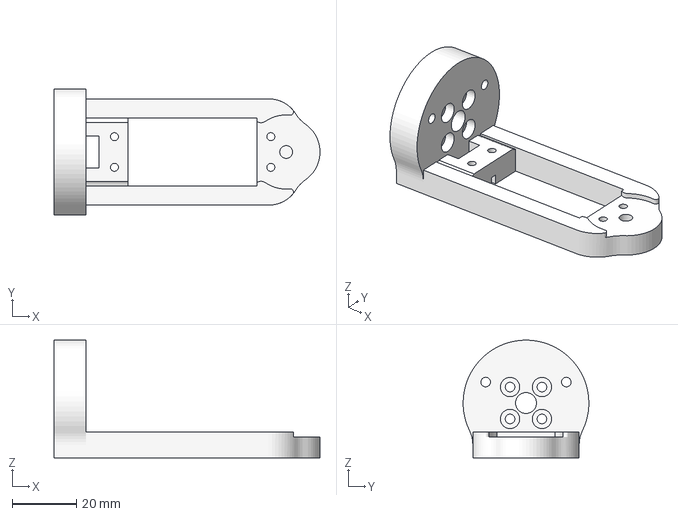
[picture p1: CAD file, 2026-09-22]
3DPrinting/Mantis MG966R Mount.3mf
82.5 x 39.0 x 36.5 mm

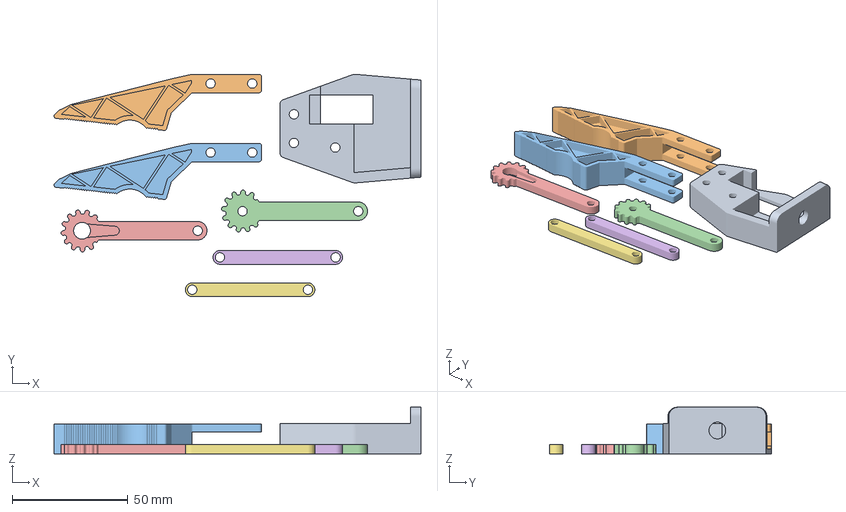
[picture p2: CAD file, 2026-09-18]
3DPrinting/Alternative gripper.3mf
158.6 x 96.1 x 20.1 mm
Base.stl
Claw.stl x 2
Connector_Gear.stl
Servo_Connector_Gear.stl
Connector.stl x 2

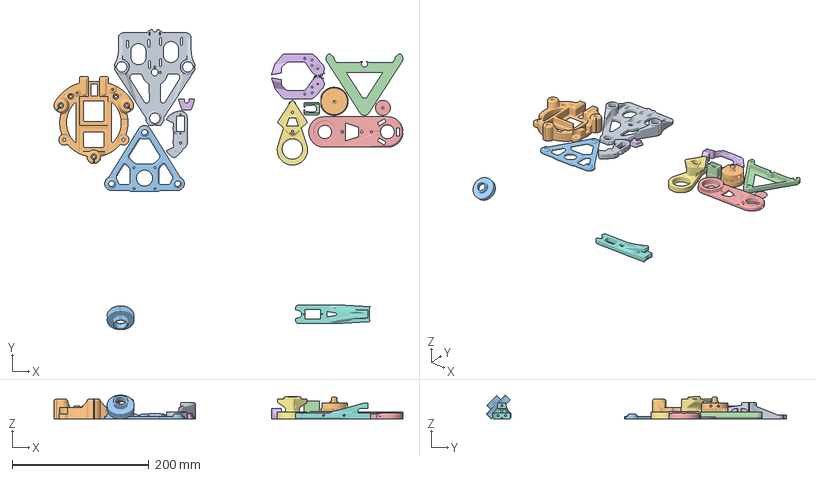
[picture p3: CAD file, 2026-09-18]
3DPrinting/Parts set.3mf
510.4 x 439.3 x 34.9 mm
Z_BASE_[V10.stl
BASEPLATE_[V10.stl
MOTORS_TRIANGLE_[V10.stl
TOP_TRIANGLE_[V10.stl
ARM_TOP_[V9.stl
GRIPPER-_NAILS_[V10.stl
ARM_BOTTOM_[V10.stl
FOREAM_[V10.stl
GRIPPER-_BASE_[V10.stl
ARM_HUB_[V11.stl
REDUCTION_[V10.stl
PEN_HOLDER_[V10.stl
CAP_[V10.stl
CABLES_CAP_[V10.stl

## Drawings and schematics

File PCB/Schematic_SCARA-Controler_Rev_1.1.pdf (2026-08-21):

### GND

### VCCServo

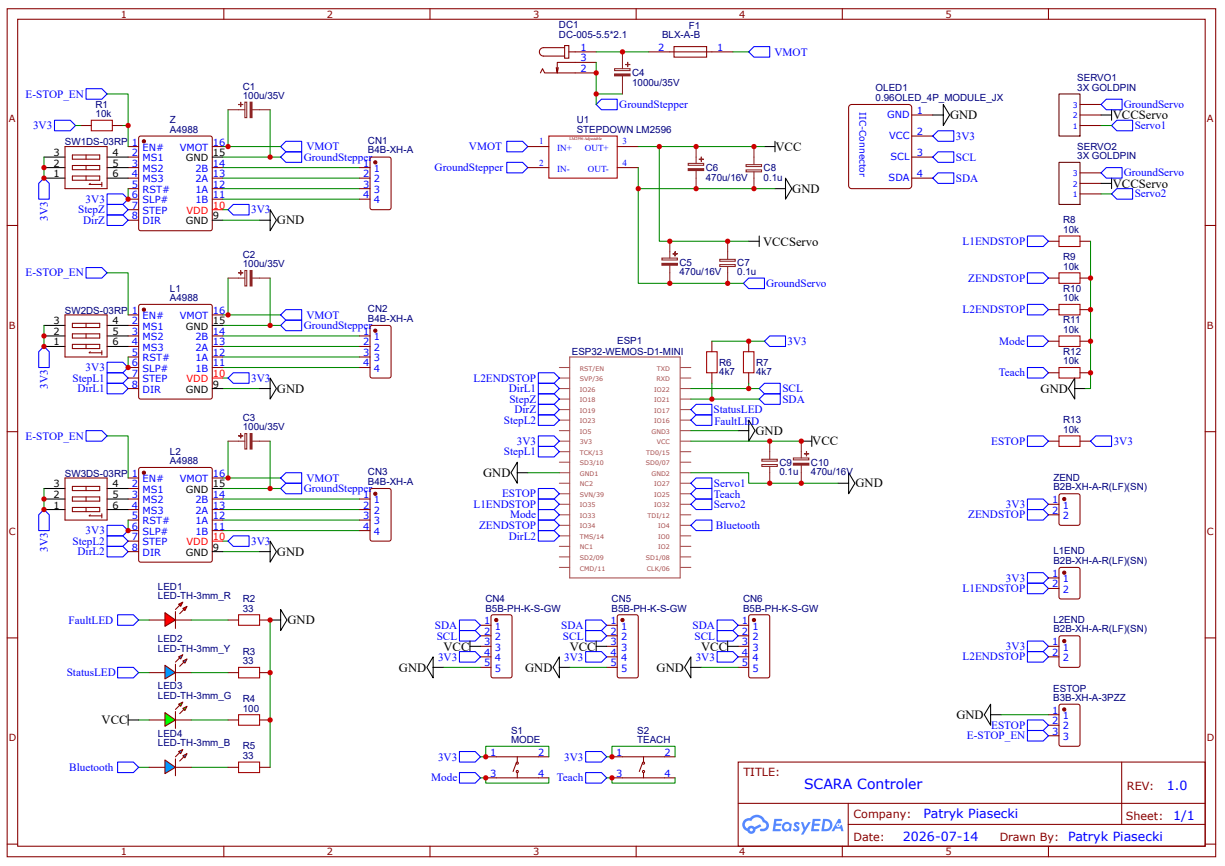
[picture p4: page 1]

Drawn By: Patryk Piasecki

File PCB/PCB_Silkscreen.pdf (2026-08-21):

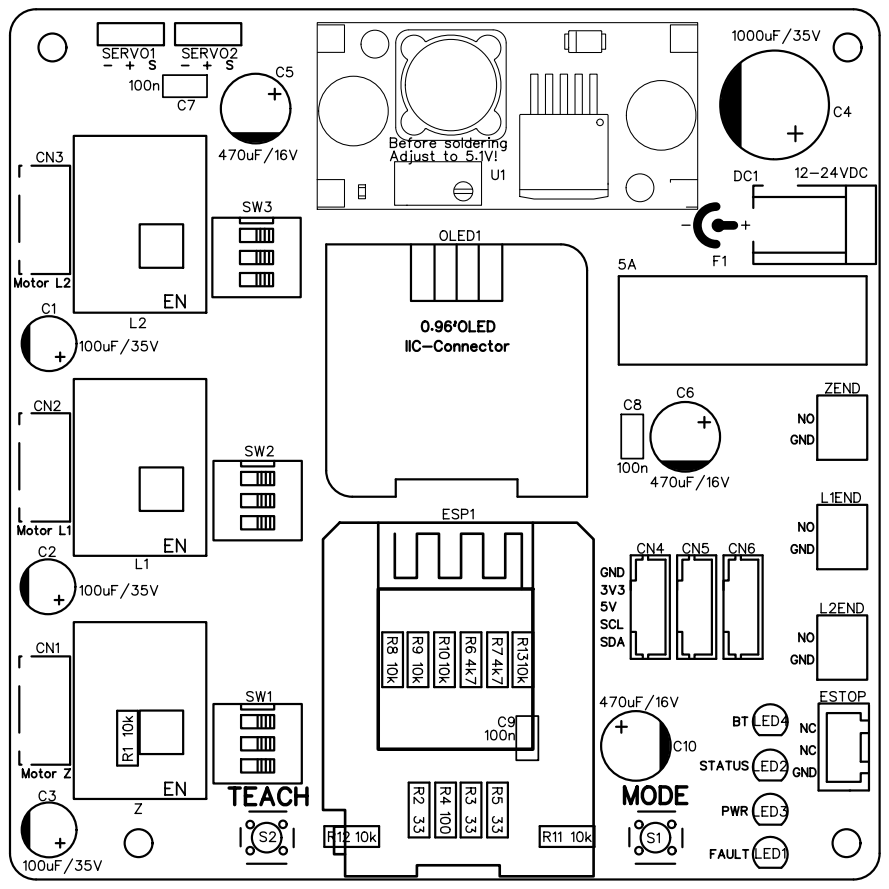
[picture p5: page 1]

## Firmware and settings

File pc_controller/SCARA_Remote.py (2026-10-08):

#!/usr/bin/env python3
"""
SCARA Remote - Windows/Linux PC controller for the ESP32 SCARA firmware.

Protocol:
  PCHELLO
  PCPAD,LX,LY,RX,RY,BUTTONS,DPAD
  PCBYE

Axes are sent as integers from -1000 to 1000.
"""

import math
import time
import tkinter as tk
from tkinter import ttk, messagebox
from collections import deque

import serial
from serial.tools import list_ports


BAUDRATE = 115200
SEND_PERIOD_MS = 50
HELLO_RETRY_S = 0.8

BTN_A = 1 << 0
BTN_B = 1 << 1
BTN_X = 1 << 2
BTN_START = 1 << 3
BTN_MODE = 1 << 4
BTN_TEACH = 1 << 5

DPAD_UP = 1 << 0
DPAD_DOWN = 1 << 1
DPAD_LEFT = 1 << 2
DPAD_RIGHT = 1 << 3


class VirtualJoystick(tk.Canvas):
    def __init__(self, master, title, size=190, **kwargs):
        super().__init__(
            master,
            width=size,
            height=size,
            highlightthickness=1,
            relief="sunken",
            **kwargs,
        )
        self.size = size
        self.center = size / 2
        self.radius = size * 0.36
        self.knob_radius = size * 0.09
        self.x_value = 0.0
        self.y_value = 0.0

        self.create_text(self.center, 14, text=title, font=("Segoe UI", 10, "bold"))
        self.create_oval(
            self.center - self.radius,
            self.center - self.radius,
            self.center + self.radius,
            self.center + self.radius,
            width=2,
        )
        self.create_line(
            self.center - self.radius,
            self.center,
            self.center + self.radius,
            self.center,
        )
        self.create_line(
            self.center,
            self.center - self.radius,
            self.center,
            self.center + self.radius,
        )
        self.knob = self.create_oval(0, 0, 0, 0, width=2)
        self.value_text = self.create_text(
            self.center, self.size - 13, text="X 0.00   Y 0.00"
        )
        self._draw_knob()

        self.bind("<Button-1>", self._move)
        self.bind("<B1-Motion>", self._move)
        self.bind("<ButtonRelease-1>", self._release)

    def _move(self, event):
        dx = event.x - self.center
        dy = event.y - self.center
        distance = math.hypot(dx, dy)
        if distance > self.radius and distance > 0:
            scale = self.radius / distance
            dx *= scale
            dy *= scale

        self.x_value = max(-1.0, min(1.0, dx / self.radius))
        self.y_value = max(-1.0, min(1.0, dy / self.radius))
        self._draw_knob()

    def _release(self, _event=None):
        self.x_value = 0.0
        self.y_value = 0.0
        self._draw_knob()

    def _draw_knob(self):
        x = self.center + self.x_value * self.radius
        y = self.center + self.y_value * self.radius
        r = self.knob_radius
        self.coords(self.knob, x - r, y - r, x + r, y + r)
        self.itemconfigure(
            self.value_text,
            text=f"X {self.x_value:+.2f}   Y {self.y_value:+.2f}",
        )

    def values(self):
        return self.x_value, self.y_value


class ScaraRemote(tk.Tk):
    def __init__(self):
        super().__init__()
        self.title("SCARA Remote - USB")
        self.geometry("930x690")
        self.minsize(850, 620)

        self.ser = None
        self.handshake_ok = False
        self.last_hello = 0.0
        self.rx_buffer = ""
        self.buttons = 0
        self.dpad = 0
        self.keys_down = set()
        self.log_lines = deque(maxlen=120)

        self.port_var = tk.StringVar()
        self.connection_var = tk.StringVar(value="Rozłączony")
        self.arm_var = tk.StringVar(value="SAFE")
        self.work_var = tk.StringVar(value="-")
        self.control_var = tk.StringVar(value="-")
        self.home_var = tk.StringVar(value="-")
        self.estop_var = tk.StringVar(value="-")
        self.relay_var = tk.StringVar(value="-")
        self.points_var = tk.StringVar(value="-")
        self.speed_var = tk.StringVar(value="-")

        self.a1_var = tk.StringVar(value="0.00°")
        self.a2_var = tk.StringVar(value="0.00°")
        self.z_var = tk.StringVar(value="0.00 mm")
        self.x_var = tk.StringVar(value="0.00 mm")
        self.y_var = tk.StringVar(value="0.00 mm")
        self.rot_var = tk.StringVar(value="0.0°")
        self.grip_var = tk.StringVar(value="0.0°")

        self._build_ui()
        self._bind_keys()
        self.refresh_ports()
        self.protocol("WM_DELETE_WINDOW", self.on_close)
        self.after(SEND_PERIOD_MS, self.tick)

    def _build_ui(self):
        top = ttk.Frame(self, padding=10)
        top.pack(fill="x")

        ttk.Label(top, text="Port COM:").pack(side="left")
        self.port_combo = ttk.Combobox(
            top, textvariable=self.port_var, width=24, state="readonly"
        )
        self.port_combo.pack(side="left", padx=(6, 6))
        ttk.Button(top, text="Odśwież", command=self.refresh_ports).pack(side="left")
        self.connect_button = ttk.Button(top, text="Połącz", command=self.toggle_connection)
        self.connect_button.pack(side="left", padx=(6, 14))

        ttk.Label(top, text="Stan:").pack(side="left")
        ttk.Label(top, textvariable=self.connection_var, font=("Segoe UI", 10, "bold")).pack(
            side="left", padx=(5, 0)
        )

        status = ttk.LabelFrame(self, text="Robot", padding=8)
        status.pack(fill="x", padx=10, pady=(0, 8))

        status_items = [
            ("A1", self.a1_var),
            ("A2", self.a2_var),
            ("Z", self.z_var),
            ("TCP X", self.x_var),
            ("TCP Y", self.y_var),
            ("ROT", self.rot_var),
            ("GRIP", self.grip_var),
            ("WORK", self.work_var),
            ("CONTROL", self.control_var),
            ("PC", self.arm_var),
            ("HOME Z", self.home_var),
            ("E-STOP", self.estop_var),
            ("RELAY", self.relay_var),
            ("Punkty", self.points_var),
            ("AUTO", self.speed_var),
        ]

        for i, (name, var) in enumerate(status_items):
            frame = ttk.Frame(status)
            frame.grid(row=i // 8, column=i % 8, padx=8, pady=3, sticky="w")
            ttk.Label(frame, text=f"{name}:").pack(side="left")
            ttk.Label(frame, textvariable=var, font=("Segoe UI", 9, "bold")).pack(
                side="left", padx=(3, 0)
            )

        control = ttk.Frame(self, padding=(10, 0, 10, 0))
        control.pack(fill="both", expand=True)

        left_col = ttk.LabelFrame(control, text="Sterowanie", padding=10)
        left_col.pack(side="left", fill="both", expand=True, padx=(0, 6))

        joy_frame = ttk.Frame(left_col)
        joy_frame.pack()
        self.left_joy = VirtualJoystick(joy_frame, "LEFT: ARM1/ARM2 lub TCP X/Y")
        self.left_joy.pack(side="left", padx=8)
        self.right_joy = VirtualJoystick(joy_frame, "RIGHT: ROT / Z")
        self.right_joy.pack(side="left", padx=8)

        button_frame = ttk.Frame(left_col)
        button_frame.pack(fill="x", pady=(12, 4))

        self._hold_button(button_frame, "A  Grip +", BTN_A).grid(row=0, column=0, padx=4, pady=4)
        self._hold_button(button_frame, "B  Grip -", BTN_B).grid(row=0, column=1, padx=4, pady=4)
        ttk.Button(
            button_frame, text="X  Relay", command=lambda: self.pulse_button(BTN_X)
        ).grid(row=0, column=2, padx=4, pady=4)
        ttk.Button(
            button_frame, text="START  JOINT/TOOL", command=lambda: self.pulse_button(BTN_START)
        ).grid(row=0, column=3, padx=4, pady=4)

        ttk.Button(
            button_frame, text="MODE  MANUAL/AUTO", command=lambda: self.pulse_button(BTN_MODE)
        ).grid(row=1, column=0, padx=4, pady=4)

        ttk.Button(
            button_frame,
            text="TEACH  Zapisz punkt",
            command=self.send_teach_command,
        ).grid(row=1, column=1, padx=4, pady=4, sticky="ew")

        ttk.Button(
            button_frame,
            text="KASUJ PROGRAM",
            command=self.confirm_clear_program,
        ).grid(row=1, column=2, padx=4, pady=4, sticky="ew")

        ttk.Button(
            button_frame,
            text="HOME Z  A+B",
            command=lambda: self.pulse_button(BTN_A | BTN_B, 320),
        ).grid(row=1, column=3, padx=4, pady=4)

        dpad_frame = ttk.LabelFrame(left_col, text="AUTO speed", padding=6)
        dpad_frame.pack(pady=(7, 0))
        ttk.Button(
            dpad_frame, text="▲ +", width=8, command=lambda: self.pulse_dpad(DPAD_UP)
        ).grid(row=0, column=1, padx=3, pady=2)
        ttk.Button(
            dpad_frame, text="◀ 100%", width=8, command=lambda: self.pulse_dpad(DPAD_LEFT)
        ).grid(row=1, column=0, padx=3, pady=2)
        ttk.Button(
            dpad_frame, text="▼ -", width=8, command=lambda: self.pulse_dpad(DPAD_DOWN)
        ).grid(row=1, column=1, padx=3, pady=2)

        help_text = (
            "Klawiatura: WASD = lewy joystick, IJKL = prawy joystick, "
            "Q/E = A/B, R = relay, SPACE = START, M = MODE, T = zapisz punkt, "
            "H = HOME Z (A+B), strzałki = D-pad AUTO.\n"
            "Po połączeniu pozostaw wszystko neutralnie przez chwilę, aż PC zmieni stan SAFE → ARMED."
        )
        ttk.Label(left_col, text=help_text, wraplength=560, justify="left").pack(
            fill="x", pady=(10, 0)
        )

        right_col = ttk.LabelFrame(control, text="Log", padding=6)
        right_col.pack(side="right", fill="both", expand=False, padx=(6, 0))
        self.log = tk.Text(right_col, width=38, height=28, state="disabled", wrap="word")
        self.log.pack(fill="both", expand=True)

        warning = ttk.Label(
            self,
            text=(
                "USB jest dodatkowym źródłem sterowania. Fizyczny E-STOP pozostaje nadrzędny. "
                "Brak pakietów z PC przez 600 ms zatrzymuje ruch."
            ),
            padding=(10, 7),
        )
        warning.pack(fill="x")

    def _hold_button(self, master, text, mask):
        btn = tk.Button(master, text=text)
        btn.bind("<ButtonPress-1>", lambda _e: self.set_button(mask, True))
        btn.bind("<ButtonRelease-1>", lambda _e: self.set_button(mask, False))
        return btn

    def _bind_keys(self):
        self.bind_all("<KeyPress>", self.key_press)
        self.bind_all("<KeyRelease>", self.key_release)

    def key_press(self, event):
        key = event.keysym.lower()
        was_down = key in self.keys_down
        self.keys_down.add(key)

        if key == "q":
            self.set_button(BTN_A, True)
        elif key == "e":
            self.set_button(BTN_B, True)
        elif key == "r":
            self.set_button(BTN_X, True)
        elif key == "space":
            self.set_button(BTN_START, True)
        elif key == "m":
            self.set_button(BTN_MODE, True)
        elif key == "t" and not was_down:
            self.send_teach_command()
        elif key == "h":
            self.set_button(BTN_A | BTN_B, True)
        elif key == "up":
            self.dpad |= DPAD_UP
        elif key == "down":
            self.dpad |= DPAD_DOWN
        elif key == "left":
            self.dpad |= DPAD_LEFT
        elif key == "right":
            self.dpad |= DPAD_RIGHT

    def key_release(self, event):
        key = event.keysym.lower()
        self.keys_down.discard(key)

        if key == "q":
            self.set_button(BTN_A, False)
        elif key == "e":
            self.set_button(BTN_B, False)
        elif key == "r":
            self.set_button(BTN_X, False)
        elif key == "space":
            self.set_button(BTN_START, False)
        elif key == "m":
            self.set_button(BTN_MODE, False)
        elif key == "t":
            pass
        elif key == "h":
            self.set_button(BTN_A | BTN_B, False)
        elif key == "up":
            self.dpad &= ~DPAD_UP
        elif key == "down":
            self.dpad &= ~DPAD_DOWN
        elif key == "left":
            self.dpad &= ~DPAD_LEFT
        elif key == "right":
            self.dpad &= ~DPAD_RIGHT

    def set_button(self, mask, pressed):
        if pressed:
            self.buttons |= mask
        else:
            self.buttons &= ~mask

    def pulse_button(self, mask, duration_ms=160):
        self.set_button(mask, True)
        self.after(duration_ms, lambda: self.set_button(mask, False))

    def pulse_dpad(self, mask, duration_ms=160):
        self.dpad |= mask
        self.after(duration_ms, lambda: setattr(self, "dpad", self.dpad & ~mask))

    def send_teach_command(self):
        if not self.ser or not self.ser.is_open or not self.handshake_ok:
            messagebox.showwarning("SCARA Remote", "Najpierw połącz aplikację z ESP32.")
            return
        self.write_line("PCTEACH")
        self.append_log("PC → ESP32: zapisz punkt TEACH")

    def confirm_clear_program(self):
        if not self.ser or not self.ser.is_open or not self.handshake_ok:
            messagebox.showwarning("SCARA Remote", "Najpierw połącz aplikację z ESP32.")
            return

        if not messagebox.askyesno(
            "SCARA Remote",
            "Skasować cały zapisany program AUTO?\n\nTej operacji nie można cofnąć.",
        ):
            return

        self.write_line("PCCLEAR")
        self.append_log("PC → ESP32: kasuj program AUTO")

    def refresh_ports(self):
        ports = list(list_ports.comports())
        values = [f"{p.device} — {p.description}" for p in ports]
        self.port_combo["values"] = values

        if values and self.port_var.get() not in values:
            preferred = next(
                (
                    value
                    for value in values
                    if any(
                        token in value.lower()
                        for token in ("cp210", "ch340", "usb serial", "uart", "esp32")
                    )
                ),
                values[0],
            )
            self.port_var.set(preferred)

    def selected_port(self):
        value = self.port_var.get().strip()
        if not value:
            return ""
        return value.split(" — ", 1)[0]

    def toggle_connection(self):
        if self.ser and self.ser.is_open:
            self.disconnect()
        else:
            self.connect()

    def connect(self):
        port = self.selected_port()
        if not port:
            messagebox.showwarning("SCARA Remote", "Wybierz port COM.")
            return

        try:
            ser = serial.Serial()
            ser.port = port
            ser.baudrate = BAUDRATE
            ser.timeout = 0
            ser.write_timeout = 0.2
            ser.dtr = False
            ser.rts = False
            ser.open()
            self.ser = ser
        except Exception as exc:
            messagebox.showerror("SCARA Remote", f"Nie można otworzyć {port}:\n{exc}")
            return

        self.handshake_ok = False
        self.last_hello = 0.0
        self.connection_var.set(f"{port} - handshake...")
        self.connect_button.configure(text="Rozłącz")
        self.append_log(f"Połączono z {port}. Oczekiwanie na ESP32...")

    def disconnect(self):
        if self.ser:
            try:
                if self.ser.is_open:
                    if self.handshake_ok:
                        self.write_line("PCPAD,0,0,0,0,0,0")
                        self.write_line("PCBYE")
                    self.ser.close()
            except Exception:
                pass

        self.ser = None
        self.handshake_ok = False
        self.buttons = 0
        self.dpad = 0
        self.connection_var.set("Rozłączony")
        self.connect_button.configure(text="Połącz")
        self.arm_var.set("SAFE")
        self.append_log("Rozłączono.")

    def keyboard_axes(self):
        lx = (-1.0 if "a" in self.keys_down else 0.0) + (
            1.0 if "d" in self.keys_down else 0.0
        )
        ly = (-1.0 if "w" in self.keys_down else 0.0) + (
            1.0 if "s" in self.keys_down else 0.0
        )
        rx = (-1.0 if "j" in self.keys_down else 0.0) + (
            1.0 if "l" in self.keys_down else 0.0
        )
        ry = (-1.0 if "i" in self.keys_down else 0.0) + (
            1.0 if "k" in self.keys_down else 0.0
        )
        return lx, ly, rx, ry

    def current_axes(self):
        mlx, mly = self.left_joy.values()
        mrx, mry = self.right_joy.values()
        klx, kly, krx, kry = self.keyboard_axes()

        lx = klx if klx != 0.0 else mlx
        ly = kly if kly != 0.0 else mly
        rx = krx if krx != 0.0 else mrx
        ry = kry if kry != 0.0 else mry

        return tuple(max(-1.0, min(1.0, value)) for value in (lx, ly, rx, ry))

    def write_line(self, line):
        if not self.ser or not self.ser.is_open:
            return
        try:
            self.ser.write((line + "\n").encode("ascii"))
        except Exception as exc:
            self.append_log(f"Błąd portu: {exc}")
            self.disconnect()

    def send_pad(self):
        lx, ly, rx, ry = self.current_axes()
        values = [int(round(v * 1000.0)) for v in (lx, ly, rx, ry)]
        self.write_line(
            f"PCPAD,{values[0]},{values[1]},{values[2]},{values[3]},"
            f"{self.buttons},{self.dpad}"
        )

    def read_serial(self):
        if not self.ser or not self.ser.is_open:
            return

        try:
            waiting = self.ser.in_waiting
            if waiting <= 0:
                return
            data = self.ser.read(waiting).decode("utf-8", errors="replace")
        except Exception as exc:
            self.append_log(f"Błąd odczytu: {exc}")
            self.disconnect()
            return

        self.rx_buffer += data
        while "\n" in self.rx_buffer:
            line, self.rx_buffer = self.rx_buffer.split("\n", 1)
            line = line.strip("\r").strip()
            if line:
                self.handle_line(line)

    def handle_line(self, line):
        if line == "PCACK,HELLO,1":
            self.handshake_ok = True
            port = self.selected_port()
            self.connection_var.set(f"{port} - połączony")
            self.append_log("ESP32: handshake OK")
            return

        if line == "PCACK,NEED_HELLO,0":
            self.handshake_ok = False
            self.append_log("ESP32 wymaga ponownego handshake.")
            return

        if line.startswith("PCACK,TEACH,"):
            result = line.split(",", 2)[2]
            if result.startswith("OK"):
                self.append_log(f"TEACH OK: {result}")
            else:
                self.append_log(f"TEACH odrzucony: {result}")
            return

        if line.startswith("PCACK,CLEAR,"):
            result = line.split(",", 2)[2]
            if result == "OK":
                self.append_log("Program AUTO skasowany.")
            else:
                self.append_log(f"Kasowanie odrzucone: {result}")
            return

        if line.startswith("PCSTATE,"):
            self.update_status(line)
            return

        self.append_log(line)

    def update_status(self, line):
        fields = {}
        for item in line.split(",")[1:]:
            if "=" in item:
                key, value = item.split("=", 1)
                fields[key] = value

        try:
            self.a1_var.set(f"{float(fields.get('A1', 0)):.2f}°")
            self.a2_var.set(f"{float(fields.get('A2', 0)):.2f}°")
            self.z_var.set(f"{float(fields.get('Z', 0)):.2f} mm")
            self.x_var.set(f"{float(fields.get('X', 0)):.2f} mm")
            self.y_var.set(f"{float(fields.get('Y', 0)):.2f} mm")
            self.rot_var.set(f"{float(fields.get('ROT', 0)):.1f}°")
            self.grip_var.set(f"{float(fields.get('GRIP', 0)):.1f}°")
        except ValueError:
            pass

        self.work_var.set(fields.get("WORK", "-"))
        self.control_var.set(fields.get("CONTROL", "-"))
        self.arm_var.set("ARMED" if fields.get("ARMED") == "1" else "SAFE")
        self.home_var.set("OK" if fields.get("HOMEZ") == "1" else "WYMAGANY")
        self.estop_var.set("AKTYWNY" if fields.get("ESTOP") == "1" else "OK")
        self.relay_var.set("ON" if fields.get("RELAY") == "1" else "OFF")
        self.points_var.set(fields.get("POINTS", "-"))
        speed = fields.get("SPEED", "-")
        self.speed_var.set(f"{speed}%")

    def append_log(self, text):
        timestamp = time.strftime("%H:%M:%S")
        self.log_lines.append(f"[{timestamp}] {text}")
        self.log.configure(state="normal")
        self.log.delete("1.0", "end")
        self.log.insert("end", "\n".join(self.log_lines))
        self.log.see("end")
        self.log.configure(state="disabled")

    def tick(self):
        if self.ser and self.ser.is_open:
            self.read_serial()
            now = time.monotonic()

            if not self.handshake_ok:
                if now - self.last_hello >= HELLO_RETRY_S:
                    self.write_line("PCHELLO")
                    self.last_hello = now
            else:
                self.send_pad()

        self.after(SEND_PERIOD_MS, self.tick)

    def on_close(self):
        self.disconnect()
        self.destroy()


if __name__ == "__main__":
    ScaraRemote().mainloop()

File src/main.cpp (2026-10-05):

// ============================================================
// PL: STEROWNIK ROBOTA SCARA
// EN: SCARA ROBOT CONTROLLER
// UA: КОНТРОЛЕР РОБОТА SCARA
// ============================================================
//
// PL: Implementacja jest podzielona na sekcje .inc, ale wszystkie są dołączane
//     do jednej jednostki kompilacji. Kolejność include ma znaczenie.
// EN: The implementation is split into .inc sections, but all of them are included
//     in a single compilation unit. Include order matters.
// UA: Реалізацію поділено на секції .inc, але всі вони підключаються
//     до однієї одиниці компіляції. Порядок include має значення.

#include "controller/00_config.inc"
#include "controller/01_motion.inc"
#include "controller/02_auto.inc"
#include "controller/03_panel_bt.inc"
#include "controller/03_startup_z_home.inc"
#include "controller/04_oled.inc"
#include "controller/05_manual_stepper.inc"
#include "controller/05_pc_serial.inc"
#include "controller/06_setup_loop.inc"

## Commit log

2026-09-11 Document manual homing and AUTO TEACH operation
2026-09-11 Slow down arm 2 and Z motion
2026-09-11 Enforce safe Z axis speed limit
2026-09-12 Match arm angular speeds and double Z speed
2026-09-12 Fix AUTO gamepad timeout handling
    [main.cpp]
2026-09-12 Fix TEACH button polarity and NVS clear handling
    [main.cpp]
2026-09-12 Fix MODE button active-high handling
    [main.cpp]
2026-09-12 Add gamepad AUTO arm speed override
2026-09-13 Shorten Z acceleration ramp by 10x
    [main.cpp]
2026-09-17 Add controller configuration for speed, BT LED and OLED
2026-09-17 Add panel state and Bluetooth LED behavior
2026-09-17 Restore AUTO D-pad speed control and stepper setup
2026-09-17 Scale Z axis with AUTO speed override
2026-09-17 Use uncapped STEP frequencies in stepper initialization
2026-09-17 Invert Z axis direction and BT LED polarity
2026-09-17 Add Ukrainian comments to OLED and servo logic
2026-09-17 Add Ukrainian comments to manual stepper control
2026-09-17 Update Polish technical documentation to current dev firmware
2026-09-17 Update Ukrainian technical documentation to current dev firmware
2026-09-18 Add 3D printing files
    [Alternative gripper.3mf, Parts set.3mf]
2026-09-18 Add editable EasyEDA PCB and schematic sources
2026-09-18 Add startup manual Z homing helper
2026-09-18 Include startup Z homing stage
2026-09-18 Show startup Z homing instructions on OLED
2026-09-18 Add gamepad-controlled startup Z homing flow
2026-09-18 Make startup Z homing stop precisely on stick release
2026-09-18 Avoid delayed panel button edges after Z homing
2026-09-18 Set servo 2 startup position to 90 degrees
2026-09-18 Limit servo 2 movement to 90-180 degrees
2026-09-18 Update README for current firmware and operating docs
2026-09-18 Update AUTO TEACH documentation for startup Z home and servo range
2026-09-19 Add relay state to controller configuration
2026-09-19 Store relay state in TEACH and restore it in AUTO
2026-09-19 Include relay and X button in controller state handling
2026-09-19 Toggle relay from gamepad X in manual mode
2026-09-19 Initialize GPIO5 relay safely at startup
2026-09-22 AUTO: add 500 ms delay after relay or servo2 action
2026-09-22 Show relay state on OLED
2026-09-22 Add files via upload
    Mantis gripper for MG966R Servo
    [Mantis MG966R Mount.3mf]
2026-09-24 Changed Arm 2 Length
2026-09-24 Set Arm2 length for Mantis gripper geometry
2026-10-04 Add linear ARM1 to ARM2 coupling coefficient
2026-10-04 Compensate linear ARM1 coupling in ARM2 motion
2026-10-04 Apply ARM2 coupling compensation in TOOL and initialization
2026-10-04 Use exact PyBot pulley ratios for ARM1 and ARM2
2026-10-04 Allow controlled TOOL elbow branch switching near extension
